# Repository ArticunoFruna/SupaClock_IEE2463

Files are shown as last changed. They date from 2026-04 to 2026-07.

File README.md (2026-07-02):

# SupaClock — Contexto y Guía del Proyecto

SupaClock es un sistema de salud inteligente usable (*wearable*) de pulsera desarrollado como parte del curso IEE2463. Su propósito es capturar biometría crítica en tiempo real, procesarla tanto en el dispositivo mediante técnicas de Inteligencia Artificial en el borde (TinyML), enviarla vía Bluetooth Low Energy (BLE) a una aplicación móvil de compañía y respaldarla de forma segura en la nube.

Este documento consolida el contexto general, características, funcionamiento de los sensores, arquitectura técnica y la organización del código según las tareas de desarrollo del proyecto.

---

## 1. Características Principales

*   **Procesamiento Concurrente y Multitarea:** Implementado bajo **ESP-IDF** (entorno oficial de Espressif) corriendo sobre **FreeRTOS** en un microcontrolador **Seeed Studio XIAO ESP32-S3** (y soportando el módulo **ESP32-C3 SuperMini** para captura de datos). Esto permite dividir el firmware en tareas con prioridades asignadas (adquisición de alta prioridad, procesamiento de actividad, interfaz gráfica e hilos de comunicación BLE).
*   **TinyML (Human Activity Recognition - HAR) en el Borde:** Inferencia en tiempo real de actividades físicas (Reposo, Caminar, Correr) ejecutada directamente en el reloj con un modelo de red neuronal convolucional 1D (CNN 1D) optimizado e integrado en C puro (`har_cnn1d`), operando con un muestreo del acelerómetro a 50 Hz.
*   **Interfaz Gráfica Integrada:** Pantalla LCD a color manejada mediante la librería gráfica **LVGL v8.4**, con refresco optimizado utilizando el bus SPI y **DMA (Direct Memory Access)** para liberar ciclos de procesamiento de la CPU.
*   **Aplicación Móvil Multiplataforma (Flutter & Dart):** 
    *   **Vista de Usuario:** Tablero interactivo con métricas en tiempo real, historial médico local e inicio de mediciones puntuales (*spot-checks*).
    *   **Procesamiento de Señales Local:** Incorpora el algoritmo **Pan-Tompkins** directamente en Dart para la detección de picos QRS y análisis de variabilidad del ritmo cardíaco (HRV) a partir de lecturas de ECG sin necesidad de servidores.
    *   **Modo Clínico:** Umbrales biométricos personalizables con lógica de estabilidad temporal para evitar falsas alarmas que disparan notificaciones locales y registros en la base de datos.
    *   **Modo Desarrollador Oculto:** Desbloqueado presionando 7 veces la versión en la pantalla de Configuración, otorgando acceso a flujos crudos de señales (ECG/IMU), grabación local a CSV e interfaz de comandos directos.
*   **Almacenamiento Local-First y Nube Serverless:** Almacenamiento local mediante Hive y sincronización asíncrona hacia Google Firebase (**Firestore** para métricas y **Storage** para las grabaciones CSV de electrocardiogramas completos), minimizando costes de infraestructura al no depender de Cloud Functions.

---

## 2. Sensores y Método de Funcionamiento

El dispositivo integra múltiples sensores biométricos conectados al bus físico común del microcontrolador.

### Resumen de Sensores
1.  **BMI160 (IMU - Unidad de Medición Inercial):** Acelerómetro y giroscopio conectados a través del bus **I2C**. Captura movimientos a 50 Hz para el algoritmo del podómetro (conteo de pasos) y para alimentar el modelo HAR en el borde.
2.  **AD8232 (ECG - Electrocardiograma):** Sensor analógico de pulso cardíaco de un solo canal. Se lee mediante el **ADC** interno del ESP32 a una frecuencia de muestreo de 500 Hz. Permite la visualización de la onda del electrocardiograma y el cálculo de intervalos RR.
3.  **MAX30102 (Pulsioxímetro):** Sensor óptico de ritmo cardíaco y saturación de oxígeno en sangre (SpO₂). Se comunica por **I2C**.
4.  **MAX30205 (Termómetro Clínico):** Sensor de temperatura de alta precisión diseñado para monitorización corporal humana. Se comunica por **I2C**.
5.  **MAX17048 (Fuel Gauge - Medidor de Batería):** Monitorea el voltaje y estado de carga de la batería Li-Po a través del bus **I2C**.

### Interfaz Física y buses de Comunicación
*   **Bus I2C (Compartido):** Los sensores BMI160, MAX30102, MAX30205 y MAX17048 comparten las líneas SDA y SCL del microcontrolador. Cada uno se identifica por su dirección de hardware hexadecimal única. Para evitar conflictos entre tareas concurrentes que acceden a este bus, el firmware emplea **Mutexes** de exclusión mutua de FreeRTOS.
*   **Bus SPI (Dedicado):** La pantalla LCD **ST7789** utiliza el bus SPI a alta velocidad con DMA para transferir buffers completos de píxeles generados en memoria RAM por LVGL.

### Protocolo de Comunicación BLE
El reloj actúa como servidor GATT y expone cuatro características principales bajo el protocolo biométrico de SupaClock:

| Característica UUID | Dirección | Descripción / Estructura del Dato |
| :--- | :--- | :--- |
| **`0xFF01`** | Notificación | **Flujo IMU Crudo:** Envío continuo a 50 Hz de paquetes de 12 bytes (`int16 ax, ay, az, gx, gy, gz`). |
| **`0xFF02`** | Notificación | **Métricas Agregadas (TLV):** Paquetes estructurados que contienen un encabezado y registros *Type-Length-Value* de variables (Ritmo cardíaco, SpO₂, Temperatura, Pasos, Batería, Estado HAR). |
| **`0xFF03`** | Notificación | **Flujo ECG Crudo:** Envío a 500 Hz de paquetes de 20 bytes que empaquetan 10 muestras consecutivas de ECG (`int16`). |
| **`0xFF04`** | Escritura | **Consola de Comandos:** Envío de órdenes al reloj (`0x00` detiene ECG, `0x01` inicia ECG, `0x02` activa depuración HAR, `0x03` detiene depuración). |

El formato **TLV (Type-Length-Value)** de la característica `0xFF02` estructura la información de la siguiente manera:
*   **Cabecera:** `Timestamp (u32)` + `Modo Energía (u8)` + `Longitud Datos (u8)`.
*   **Tipos de Registro (Types):**
    *   `0x01`: Frecuencia Cardíaca (BPM y calidad de señal).
    *   `0x02`: Saturación de Oxígeno (SpO₂ y calidad de señal).
    *   `0x03`: Temperatura Corporal.
    *   `0x04`: Estado de la Batería.
    *   `0x05`: Conteo de Pasos.
    *   `0x08`: Estado de Actividad HAR Consolidado.

---

## 3. Estructura de Directorios y Tareas de Desarrollo

El código fuente del proyecto se encuentra estructurado en carpetas dedicadas según el área de ingeniería y desarrollo:

```
SupaClock_IEE2463/
├── app/                  # Aplicación móvil en Flutter (Frontend y lógica del teléfono)
├── src/                  # Entrypoint del firmware y pruebas en ESP-IDF
├── lib/                  # Librerías internas y drivers de hardware para PlatformIO
├── hardware/             # Esquemáticos y PCB (diseño electrónico en Eagle/Kicad)
├── mechanical/           # Modelado en 3D del chasis y botón del reloj (OpenSCAD/STL)
├── tools/                # Scripts de Python para entrenamiento, simulaciones y debug
├── data_ml/              # Base de datos local de acelerometría para entrenamiento HAR
├── docs/                 # Hojas de datos (Datasheets), especificaciones y entregables
├── pc_simulator/         # Simulador de la interfaz gráfica en PC
└── scripts/              # Herramientas auxiliares y de generación de recursos gráficos
```

### 📂 Distribución de Tareas y Directorios de Trabajo

#### 1. Tareas de Firmware (C y C++ sobre ESP-IDF / FreeRTOS)
*   **Directorio principal de código:** [src/](file:///home/jay-c/Desktop/SupaClock_IEE2463/src) y [lib/](file:///home/jay-c/Desktop/SupaClock_IEE2463/lib)
*   **Configuración del entorno:** [platformio.ini](file:///home/jay-c/Desktop/SupaClock_IEE2463/platformio.ini) define los parámetros de compilación y dependencias.
*   **Controladores de sensores:** Ubicados en `lib/` bajo los nombres de cada driver:
    *   `bmi160_driver/` (Acelerómetro/Giroscopio)
    *   `max30102_driver/` (Pulsioximetría)
    *   `max30205_driver/` (Temperatura)
    *   `max17048_driver/` (Batería)
    *   `ad8232_driver/` & `ad8232_c3_driver/` (Electrocardiografía)
*   **Motor Gráfico (LVGL) y UI del Reloj:** Se trabaja en [lib/supaclock_ui/](file:///home/jay-c/Desktop/SupaClock_IEE2463/lib/supaclock_ui), [lib/ui_theme/](file:///home/jay-c/Desktop/SupaClock_IEE2463/lib/ui_theme) y [lib/ui_fonts/](file:///home/jay-c/Desktop/SupaClock_IEE2463/lib/ui_fonts).
*   **TinyML (CNN 1D) e Inferencia:** La lógica de red neuronal se encuentra en [lib/har_cnn1d/](file:///home/jay-c/Desktop/SupaClock_IEE2463/lib/har_cnn1d).
*   **Infraestructura BLE:** Las definiciones del protocolo e hilos de transmisión están en [lib/ble_telemetry/](file:///home/jay-c/Desktop/SupaClock_IEE2463/lib/ble_telemetry).
*   **Pruebas de Componentes:** Código para validar hardware de forma aislada en [src/tests/](file:///home/jay-c/Desktop/SupaClock_IEE2463/src/tests) (por ejemplo, tests de pantalla, BLE, sensores específicos o algoritmos particulares).

#### 2. Tareas de Desarrollo Móvil (Flutter & Dart)
*   **Directorio de trabajo:** [app/](file:///home/jay-c/Desktop/SupaClock_IEE2463/app)
*   **Interfaz de Usuario:** Vistas e interfaces en [app/lib/screens/](file:///home/jay-c/Desktop/SupaClock_IEE2463/app/lib/screens) (dashboard, settings, spot-check, dev-mode).
*   **Persistencia Local y Backend (Firebase):** Configuración de bases de datos y sincronización en [app/lib/services/](file:///home/jay-c/Desktop/SupaClock_IEE2463/app/lib/services) (`firestore_service.dart`, `storage_service.dart`, `local_store.dart` usando Hive).
*   **Procesamiento de Señal (ECG) y BLE:** Algoritmo Pan-Tompkins en `app/lib/services/pan_tompkins.dart` y parseo de tramas de telemetría en `app/lib/services/ble_service.dart`.
*   **Modelos de Datos:** Declarados en [app/lib/models/](file:///home/jay-c/Desktop/SupaClock_IEE2463/app/lib/models) para asegurar concordancia con Firebase.

#### 3. Tareas de Machine Learning y Análisis Científico (Python)
*   **Entrenamiento y Reentrenamiento HAR:** Los scripts para construir el modelo de actividad física se encuentran en [tools/train_har_cnn.py](file:///home/jay-c/Desktop/SupaClock_IEE2463/tools/train_har_cnn.py) y [tools/train_har_cnn_c3.py](file:///home/jay-c/Desktop/SupaClock_IEE2463/tools/train_har_cnn_c3.py).
*   **Recopilación de Datasets:** El historial de datasets recopilados clasificados para entrenar el clasificador se trabaja en [data_ml/](file:///home/jay-c/Desktop/SupaClock_IEE2463/data_ml) (ej. resting, walking, running, stairs).
*   **Reproducción y Debug del Modelo (Replay):** Script [tools/har_replay.py](file:///home/jay-c/Desktop/SupaClock_IEE2463/tools/har_replay.py) corre el modelo `.tflite` sobre logs de acelerometría y simula los filtros de suavizado.
*   **Calibración y Simulación de Umbrales:** `tools/calibrate_steps.py` (conteo de pasos) y `tools/debug_pt.py` (simulador Pan-Tompkins).
*   **Monitoreo del Hardware:** [tools/supaclock_monitor.py](file:///home/jay-c/Desktop/SupaClock_IEE2463/tools/supaclock_monitor.py) es una aplicación de escritorio para graficar ondas IMU/ECG y enviar comandos por puerto serie/BLE.

#### 4. Tareas de Diseño de Hardware (Electrónica / PCB)
*   **Directorio de trabajo:** [hardware/](file:///home/jay-c/Desktop/SupaClock_IEE2463/hardware)
*   Contiene los esquemáticos y placas (`.sch` y `.brd`) para el circuito portador del reloj, el módulo ECG AD8232 y el módulo medidor de batería, además de scripts de soporte de conexión como `build_v4_schematics.py` o `dump_nets.py`.

#### 5. Tareas de Diseño Mecánico (Carcasa y Botones)
*   **Directorio de trabajo:** [mechanical/](file:///home/jay-c/Desktop/SupaClock_IEE2463/mechanical)
*   Lugar donde se diseñan las cubiertas (superior, inferior y botones) en OpenSCAD (`.scad`) y se exportan a STL para manufactura mediante impresión 3D (`mechanical/stl/`, `mechanical/stl_v3/`).

#### 6. Tareas de Documentación del Proyecto
*   **Directorio de trabajo:** [docs/](file:///home/jay-c/Desktop/SupaClock_IEE2463/docs)
*   Incluye los manuales de arquitectura y conceptos (`docs/arquitectura_conceptos.md`), guías para nuevos desarrolladores (`docs/guia_introductoria.md`), protocolos de comunicación (`docs/ble_har_protocol.md`), resúmenes de avances e informes para las evaluaciones académicas del curso (`docs/Entrega1` a `docs/Entrega4`).

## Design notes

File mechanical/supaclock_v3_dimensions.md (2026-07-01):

# SupaClock V3 — Hoja de cotas

Análoga a `supaclock_v2_dimensions.md`. Cambios clave vs V2:

- Altura total reducida de **25 mm → 17 mm** (XIAO SMD soldado directo, sin pin sockets).
- Bottom case **al ras** (sin pocket de pila). Standoffs reducidos a la mitad (1 mm vs 2 mm).
- Pila Sony WF-1000XM5 case (prismática ~30 × 20 × 5 mm) **colgada del techo** con cinta 3M VHB doble faz (0.5 mm) sobre la zona del display.
- Top case con sistema **plug-and-play** para faceplate intercambiable (snap-fit ó magnetic).
- Botones laterales V2 (stem horizontal) **inalterados**: switch nuevo 3×7×3.5 mm side-press pegado plano sobre la PCB con super-glue gel, plunger apuntando a +X, cables soldados a pads SMD originales.
- Heat-set inserts M3 para tornillería desmontable (igual que V2: Ø4.2 × 5 mm).

Todas las medidas en milímetros.

---

## 1. Sistema de coordenadas

Idéntico a V2:

```
            Z (vertical, hacia arriba)
            |
            |
            +------ X (largo, eje izq-der del reloj puesto)
           /
          /
         Y (corto, eje proximal-distal en la muñeca)

Origen: esquina INFERIOR-IZQUIERDA-FRENTE del envelope exterior
```

- **Bottom case**: Z = 0 a Z = 3 (cara Z=0 toca la piel)
- **Seam (unión)**: plano horizontal en Z = 3
- **Top case**: Z = 3 a Z = 17 (en frame top-case-local: Z = 0 a 14)
- **Faceplate** (cosmético, intercambiable): Z = 17 a Z = 19 (sumando 2 mm de techo decorativo)

Conversión PCB-local ↔ case-local:
```
X_case = X_pcb + pcb_off_x = X_pcb + 6.5
Y_case = Y_pcb + pcb_off_y = Y_pcb + 6.0
```

---

## 2. Envelope exterior

| Parámetro | Valor | Notas |
|---|---|---|
| Ancho (X) | 98.0 mm | base. Top está INSET por `taper` |
| Largo (Y) | 79.0 mm | base. Top está INSET por `taper` |
| **Alto (Z) core** | **17.0 mm** | core sin faceplate (vs V2 25.0) |
| Alto con faceplate snap | 19.0 mm | +2 mm de skin decorativo |
| Alto con faceplate magnetic | 19.0 mm | idem |
| r_vert | 12.0 mm | radio de las 4 esquinas verticales |
| r_chamfer | 1.5 mm | chamfer en Z=0 y Z=15.5 |
| taper | 2.0 mm | reducción lineal radio entre Z=0 y Z=15.5 |

---

## 3. Bottom case — features (al ras)

| Feature | Posición (X, Y) | Z | Dimensiones | Notas |
|---|---|---|---|---|
| Piso | toda la base | 0 — 2 | 2 mm grosor | esquinas redondeadas |
| Cavidad | toda | 2 — 3 | abierta arriba | offset 2 mm desde envelope |
| Standoff MH1 | (10.0, 69.5) | 2 — 3 | Ø7 OD, Ø3.2 ID | **1 mm** (mitad de V2) |
| Standoff MH2 | (88.0, 69.5) | 2 — 3 | Ø7 OD, Ø3.2 ID | idem |
| Standoff MH3 | (10.0, 9.5) | 2 — 3 | Ø7 OD, Ø3.2 ID | idem |
| Standoff MH4 | (88.0, 9.5) | 2 — 3 | Ø7 OD, Ø3.2 ID | idem |
| Cutout MAX30102 | centro (52.0, 39.195) | 0 — 2 | **17 × 22 mm (X×Y)** | sensor PPG, rotado 90° vs V2 (lado largo en Y) para calzar orientación real del sensor en PCB v3 |
| Cutout MAX30205 | centro (51.5, 23.0) | 0 — 2 | 14 × 10 mm | sensor temp |
| Electrode RA | centro (18.5, 37.5) | 0 — 2 | Ø6 mm | M3 a piel |
| Electrode LA | centro (72.0, 38.0) | 0 — 2 | Ø6 mm | M3 a piel |
| Electrode RL | centro (50.0, 10.0) | 0 — 2 | Ø6 mm | M3 a piel |

**Sin pocket de pila** → cara contra la piel completamente plana.

---

## 4. Top case core — features

Frame local: Z=0 = seam, Z=14 = cara exterior del techo (cubierta por el faceplate).

| Feature | Posición (X, Y) | Z (local top) | Dimensiones | Notas |
|---|---|---|---|---|
| Cavidad | toda | 0 — 12 | abierta abajo | techo a Z=12, interior alcanza 12 |
| Techo | toda | 12 — 14 | 2 mm grosor | con ventana display |
| Pilar P1-P4 (4) | (10/88, 9.5/69.5) | 0 — 12 | Ø7 OD, Ø4.2 ID × 5 mm | heat insert M3 (insert depth 5) |
| **Ventana display** | centro (50.78, 44.5) | 10 — 14 | **28 × 34 mm** | atraviesa techo + faceplate alineado |
| Botón SW1 | (96, 21.375, btn_z=3.5) | 3.5 ± 2.1 | Ø4.2 mm | atraviesa pared +X, eje X (V2 idéntico) |
| Botón SW2 | (96, 33.875, btn_z=3.5) | 3.5 ± 2.1 | Ø4.2 mm | idem (V2 idéntico) |
| **USB-C** | (96, 54, usb_z=3.6) | 3.6 ± 3.5 | 13 × 7 mm rect | pared +X. **z_above_pcb reducido a 2** vs V2 (14) por XIAO SMD soldado |
| **Jack 3.5 ECG** | (0, 24.586, jack_z=6.1) | 6.1 ± 3.25 | Ø6.5 thread pasante + Ø12 rebaje (prof 1 mm en la pared) | pared **-X**. Mismo `jack_y_pcb` que V2; `z_above_pcb` bajado de 12.6 → 4.5. Rebaje **NO atraviesa** la pared (deja 1 mm interior con solo el thread). Conecta a J13 PCB v3 vía cables manuales |
| **Marca VHB pila** | centro (50.78, 44.5) | 12 (cara interior techo) | 30 × 20 mm rectángulo | indentación 0.3 mm de profundidad para guiar la cinta VHB |

> **Tabs L para la pila — DESHABILITADOS en V3.1.** La zona donde irían los tabs (X=35–67, Y=34–55) coincide con la huella del display + adapter PCB y puede colisionar. Hasta confirmar medidas reales del PCB+adapter, sólo dejamos la marca VHB. El código `battery_tab()` y `battery_tabs_all()` se preserva en el SCAD comentado para reactivar cuando se confirme el clearance.

### 4.1 Retention faceplate — V3.3 diagonal limpia

**Esquema diagonal SW-NE**: solo 2 imanes redondos en la diagonal SW-NE. Las otras 2 esquinas (SE-NW) **quedan limpias, sin agujeros**. Sin pines guía.

#### Modo MAGNETIC

| Parámetro | Valor |
|---|---|
| Imanes | **2 pares de N42 Ø7 × 1.5 mm** (4 total, diámetro = cabeza M4) |
| Posición imanes | esquinas **SW y NE** (diagonal), a 6 mm del borde |
| Hueco imán | Ø7.2 × 1.6 mm (holgura 0.2/0.1) |
| Otras 2 esquinas (SE, NW) | **sin features** (lisas) |
| Fuerza atracción por par | ~0.7 kg |
| Fuerza total ensamble | ~1.4 kg |
| Ciclos | infinitos |
| Alineación angular | los 2 imanes en diagonal restringen rotación; el ajuste perimetral del faceplate al borde del core complementa |
| Polaridad | N hacia arriba en core, S hacia abajo en face |
| Fijación imán | super-glue gel dentro del hueco |
| Tapa cosmética | 0.4 mm de PLA debajo del imán en core (techo 2 mm, hueco 1.6) |

#### Modo SNAP

| Parámetro | Valor PLA eSun PLA+ |
|---|---|
| Cantilevers | **4 idénticos** (faceplate macho, core hembra) |
| Cantilever largo × espesor | 5 × 1.4 mm |
| Hook engagement | 0.4 mm |
| Fillet base | 0.5 mm |
| Insertion / extraction | ~5 N / ~9 N |
| Ciclos | 30–40 |

---

## 5. Faceplate (skin intercambiable)

Pieza separada, snap o magnetic. Z=17 a Z=19.

| Feature | Posición | Dimensiones | Notas |
|---|---|---|---|
| Slab base | toda | 98 × 79 × 1.5 mm | sigue contorno del top exterior (radio 10 mm = r_vert − taper) |
| Ventana display | centro (50.78, 44.5) | 28 × 34 mm (alineada con techo core) | atraviesa todo el faceplate |
| Bezel display | anillo alrededor de la ventana | 32 × 38 mm exterior, 28 × 34 interior | recess 0.3 mm para "vidrio" cosmético |
| Marcas horarias / decoración | según `style` | grabadas 0.4 mm de profundidad | mode-dependiente |
| Retention macho (snap) | 4 cantilevers internos | 5 mm largo × 1.4 mm espesor | cuando `retention=snap` |
| Cavidades imanes (magnetic) | 4 huecos esquinas | Ø5.2 × 2.1 mm | cuando `retention=magnetic` |
| Pin guía | 2 cilindros Ø2 mm | sale de la cara inferior 3 mm | siempre presente |

### 5.1 Variantes de estilo

- **`style="minimal"`**: PLA Black, sin decoración, sólo bezel display.
- **`style="classic"`**: bezel display + 12 marcas horarias (Ø1 mm cada una) a 16 mm del centro, grabadas 0.4 mm. Color sugerido: PLA Silver/Grey.
- **`style="sport"`**: bezel display + numerales 5/15/25/35/45/55 en relieve negativo a 18 mm del centro. Color sugerido: PLA Orange.

---

## 6. Pila colgada del techo

Pila Sony WF-1000XM5 case (~30 × 20 × 5 mm, LiPo prismática) **con conector JST PH 2.0 mm** previamente soldado.

| Item | Valor |
|---|---|
| Posición de la pila (cara interior techo) | centrada en (50.78, 44.5) en case-local |
| Footprint | 30 × 20 mm |
| Altura pila | 5 mm |
| Adhesivo | cinta 3M VHB 5952 (0.5 mm espesor) doble faz |
| Marca en el techo | indentación rectangular 0.3 mm de profundidad para guiar el VHB |
| Salida cable JST | lado **-X** de la pila → recorrido ~25 mm hasta MAX17048 en (~17, 50) PCB-local |
| Gap pila ↔ display | ~1.5 mm (pila a Z=7..12, display a Z=1.6..5.6 en top-local) |

**Importante**: NO pegar con cyanoacrylate sobre la pila (riesgo térmico). VHB de doble faz es la opción correcta para baterías LiPo.

---

## 7. Stack vertical detallado

```
Z = 17.0  ── cara exterior FACEPLATE ──
Z = 15.0     base FACEPLATE (1.5 mm slab + 0.5 retention)
Z = 15.0  ── cara exterior TECHO core ──
Z = 13.0     espesor techo
Z = 13.0  ── cara interior techo ──
Z = 12.5     VHB 3M (0.5 mm)
Z = 12.5  ── cara superior pila ──
Z = 7.5      pila (5 mm)
Z = 7.5   ── cara inferior pila ──
Z = 6.0      gap pila ↔ display (1.5 mm)
Z = 6.0   ── cara superior display ──
Z = 4.6      display + adapter (1.6 + 2.4)
Z = 4.6   ── cara superior PCB ──
Z = 3.0      PCB FR-4 (1.6 mm)
Z = 3.0   ── cara inferior PCB / seam ──
Z = 2.0      standoff (1 mm, mitad de V2)
Z = 2.0   ── cara interior bottom ──
Z = 0.0      piso bottom (2 mm)
Z = 0.0   ── cara contra PIEL ──
```

(Heights en frame **abs**, no top-local).

---

## 8. Standard parts (compra fuera)

| Parte | Especificación | Cant | Notas |
|---|---|---|---|
| Perno M3 | M3 × 6 mm cabeza redondeada | 4 | bottom → top via heat insert |
| Heat insert M3 | M3 × 5 mm OD Ø4.0–4.2 | 4 | embebidos en pilares top |
| Spring bar | Ø1.5 × largo 22 mm | 4 | tienda relojes |
| Correa | 20 mm cualquier estilo | 1 | tienda relojes |
| Perno M3 (electrodo) | M3 × 8 mm acero inox cabeza redonda | 3 | electrodos ECG |
| Tuerca M3 (electrodo) | M3 estándar | 3 | electrodos ECG |
| Imán neodimio N42 | Ø5 × 2 mm | 4 | sólo si `retention=magnetic` |
| Cinta VHB 3M 5952 | 0.5 mm doble faz | 30 × 20 mm | pila colgada |
| Switch tactile | 3 × 7 × 3.5 mm side-press SMD | 2 | el que ya tenés |
| Cable 30 AWG | flexible silicone | 4× 30 mm | soldar switch nuevo a pads SMD |
| Super-glue gel | cyanoacrylate gel | 1 frasco | pegar switches PLANOS sobre PCB |

---

## 9. Validación rápida

| Verificación | Valor esperado |
|---|---|
| Ancho exterior máximo (Z=0) | 98.0 |
| Ancho exterior máximo (Z=15) | 94.4 (= 98 − 2 × taper × 15/17) |
| H_total core | 17.0 |
| H_total con faceplate | 19.0 |
| Distancia entre lugs (inner mismo lado) | 20.0 |
| Distancia entre standoffs MH1-MH2 | 78.0 |
| Altura interior arriba del PCB | 10.4 |
| Distancia desde piel (Z=0) al centro del display | 6.5 |
| Distancia desde piel al centro USB-C | 4.6 (= 3 + 1.6) |
| Volumen aproximado del case completo | ~75 cm³ |

---

*Archivos relacionados:*
- `supaclock_v3_bottom_case.scad`
- `supaclock_v3_top_case.scad`
- `supaclock_v3_faceplate.scad`
- `supaclock_v3_button_caps.scad` (reuse del v2)
- `supaclock_v3_assembly.scad`

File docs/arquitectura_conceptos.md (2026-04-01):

# Guía Completa: Arquitectura y Conceptos del Proyecto SupaClock

Esta guía está diseñada para llevar a un programador con conocimientos básicos (por ejemplo, alguien que ha utilizado la plataforma Arduino y la función `loop()`) hacia el entendimiento de una arquitectura profesional utilizando un Sistema Operativo en Tiempo Real (RTOS), desarrollo móvil moderno y bases de datos en la nube.

---

## 1. De Arduino a ESP-IDF (FreeRTOS)

En un programa clásico de Arduino, el código funciona de manera **secuencial**: hay un `setup()` que inicializa los pines y un `loop()` infinito que se repite una y otra vez. El problema de esta estrategia (llamada "Super-Loop") es que si utilizas un `delay()` o si la lectura de un sensor tarda mucho, **todo el sistema se congela**. No puedes actualizar la pantalla y medir la frecuencia cardíaca al mismo tiempo.

Para solucionar esto, SupaClock no usa el entorno básico de Arduino, sino que usa **ESP-IDF** (el entorno oficial de Espressif en lenguaje C puro) operando sobre **FreeRTOS** (Free Real-Time Operating System).

### ¿Qué es FreeRTOS y sus Tareas?
FreeRTOS es un mini-sistema operativo para microcontroladores. Nos permite dividir nuestro código en **Tareas (Tasks)**, como si tuviéramos múltiples `loop()` ejecutándose al mismo tiempo (Multitasking o Concurrencia). 
El ESP32-C3 solo tiene un "procesador" (un solo núcleo), pero FreeRTOS cambia tan rápido de una tarea a otra (en milisegundos) que parece que todo ocurre a la vez.

En SupaClock se definen tareas con **prioridades**:
1. **Tarea de Adquisición (Prioridad Alta):** Constantemente lee los sensores. Como medir el pulso o la temperatura es crítico, si esta tarea necesita funcionar, FreeRTOS pausa a las demás de inmediato y le presta el procesador.
2. **Procesamiento Edge (Prioridad Media):** Aplica matemáticas a lo que leyó la tarea anterior (ej. contar pasos, deducir la postura con *TinyML*).
3. **Interfaz Gráfica (Prioridad Media-Baja):** Dibuja los números en la pantalla LCD (LVGL) y lee cuando oprimes un botón.
4. **Comunicaciones BLE (Prioridad Baja):** Se encarga de empaquetar y enviar inalámbricamente los resultados por Bluetooth.

### Protegiendo la Memoria: Queues y Mutexes
Al tener cosas pasando "al mismo tiempo", hay riesgos:
* **El problema:** ¿Qué pasa si la Tarea 1 intenta guardar datos en una variable, y justo en ese milisegundo la Tarea 2 intenta leer esa misma variable? Podría leer basura.
* **Solución 1 (Queues o Colas):** Son buzones de mensajes de FreeRTOS. La Tarea de Adquisición lee 50 valores del acelerómetro y los mete en un buzón de forma segura. La Tarea de Procesamiento los saca del buzón uno a uno para analizarlos.
* **Solución 2 (Mutex):** "Mutex" significa Exclusión Mutua. Funciona como la **llave del baño**. Si tenemos tres sensores conectados al mismo cable físico (I2C) y la Tarea 1 quiere leer un sensor, toma la llave (Mutex). Si durante ese instante la Tarea 3 quiere leer otro sensor del mismo cable, debe cruzar los brazos y esperar a que la Tarea 1 suelte la llave. Así evitamos colisiones catastróficas.

---

## 2. Conceptos de Hardware y Protocolos (Explicado desde cero)

Tu microcontrolador ESP32-C3 tiene un número muy limitado de pines físicos. Si intentas conectar 4 sensores avanzados asignando cables y pines separados para cada dato, te quedarías sin pines casi de inmediato. Por ello, se utilizan "Protocolos de Bus", que permiten compartir cables entre muchos chips.

### Bus I2C (Inter-Integrated Circuit)
Se podría traducir como el "Bus de 2 cables". Es un protocolo donde todos los sensores biométricos de SupaClock comparten **solo 2 cables**:
1. **SCL (Reloj):** El cable donde el ESP32 marca el ritmo o velocidad de la conversación.
2. **SDA (Datos):** El cable por donde viajan los "1s y 0s" (los mensajes).

**¿Cómo funciona si todos comparten el mismo cable?**
Funciona como si el ESP32 fuera el profesor de una sala de clases, y cada sensor es un alumno con un "nombre" numérico único (Llamado **Dirección Hexadecimal**). 
Si el ESP32 grita por el cable SDA: *"¡Alumno 0x57, entrégame tu tarea!"*, solo el Oxímetro (MAX30102) le responde, mientras el Termómetro (MAX30205, dirección `0x48`) ignora el mensaje. 
Esto permite conectar el Oxímetro, el Termómetro, el Giroscopio y el Medidor de Batería, usando solamente 2 pines del ESP32.

### Bus SPI (Serial Peripheral Interface)
I2C es genial para sensores, pero es muy lento para mover gráficos hacia una pantalla a color. Para la pantalla LCD ST7789, usamos SPI.
SPI usa más cables que I2C, pero es una vía rápida dedicada que opera como una autopista de varias pistas:
* **SCK:** El ritmo de reloj (mucho más rápido que I2C).
* **MOSI:** El canal de ida (Master Out, Slave In). El ESP32 le escupe píxeles de colores a la pantalla por aquí.
* **CS (Chip Select):** Un cable extra que actúa como un "switch". Cuando el ESP32 lo pone en LOW, le dice a la pantalla *"Hey, pon atención que lo que va a pasar por el cable MOSI es una foto para ti"*. 

### El DMA (Direct Memory Access)
Imagina que eres un arquitecto construyendo un muro muy largo. Podrías tomar ladrillo por ladrillo y llevarlo caminando (es decir, el procesador del ESP32 lee un píxel de su memoria y lo manda a la pantalla, uno a uno). Si lo haces así, tú (la CPU del ESP32) no puedes hacer nada más; estás esclavizado llevando píxeles.

El **DMA** es como contratar a un ayudante por hardware físico. El código del ESP32 (usando una librería gráfica llamada LVGL) "dibuja" en su memoria interna una imagen completa de la pantalla. Luego, el ESP32 le dice al DMA: *"Hey DMA, toma todos estos 10.000 píxeles y bombéalos hacia la pantalla por la vía SPI lo más rápido que puedas. Yo me voy a seguir midiendo la actividad cardíaca."*
El resultado: la pantalla se refresca de la nada, fluidamente, sin costarle recursos valiosos de cálculo matemático a la CPU.

### ADC (Conversor Análogo a Digital)
El mundo real no son `1` ni `0`; la corriente eléctrica de tu corazón es analógica (como una ola infinita y suave). El chip encargado del ECG (AD8232) extrae tus latidos tocando los tornillos metálicos, y saca un pequeñito voltaje que sube y baja.
El **ADC** del ESP32 es la compuerta que lee esa olita de voltaje y, miles de veces por segundo, la convierte a números enteros (ej. de 0 a 4095) para que el código en C la pueda entender y matemáticas.

---

## 3. El Mundo Móvil: App y Flutter (Explicado desde cero)

### ¿Qué es Flutter y por qué se usa?
Tradicionalmente, si querías crear una App para que se conecte a un de hardware, necesitas saber programar en **Kotlin o Java** (para teléfonos Android) y otro código completamente distinto en **Swift** (para iPhones). Esto dobla el trabajo.
**Flutter** es una herramienta moderna creada por Google utilizando el lenguaje de programación **Dart**. Nos permite diseñar una aplicación escribiendo el código de las pantallas **una sola vez**, y Google se encarga de compilar ese código para que funcione de forma idéntica en Android e iOS.
En Flutter todo es un "Widget". Un botón es un widget que va dentro de una Lista, que es un widget, que va dentro de una Ventana (widget). Modificar pantallas móviles consiste en agrupar visualmente estas cajas de construcción abstractas.

### ¿Cómo se comunican el Reloj y el Celular? (Bluetooth BLE)
Se utiliza un protocolo llamado **Bluetooth Low Energy (BLE)**, el cual es muy diferente al Bluetooth clásico de los audífonos (que chupan muchísima batería al estar siempre activos transmitiendo audio).

El BLE opera mediante la lectura de "pizarras":
* **El Servidor (SupaClock):** El ESP32 funciona como una pizarra dividida en secciones lógicas (llamadas **Servicios**). En la sección 'Batería' escribe un '80%'. En la sección 'Frecuencia Cardíaca' escribe '90 ppm'. Estas cajitas pequeñas donde escribe los números exactos se llaman **Características GATT**.
* **El Cliente (La App del Celular):** El teléfono encuentra el reloj, se conecta, y no pide la información cada 5 minutos, sino que **se subscribe** a la característica de 'Frecuencia Cardíaca'.
* **Notificaciones:** El reloj actualiza el texto en su "pizarra" solo 1 vez por segundo (1 Hz). Cuando el número cambia a '91 ppm', pasivamente la antena le "notifica" (Notify) a la App del celular para que mueva sus gráficos. Es un diseño altamente ahorrativo en batería.

---

## 4. El Backend y la Nube: Firebase (Explicado desde cero)

### ¿Qué es el "Backend" y qué es "Serverless"?
Al construir una app completa, necesitas un puente permanente que guarde en la nube los registros del reloj para que no se pierdan cuando el celular se apague. Históricamente tendrías que arrendar una torre de computadora real en Amazon (un "Servidor"), instalar Linux, configurar una base de datos MySQL, gestionar la seguridad, y rezar para que si se corta su luz, puedas reiniciarlo.

**Firebase** es un ecosistema de Google enfocado en la arquitectura "Serverless" (Sin Servidor propio). En este formato, tú no configuras una computadora virtual, ni sabes en qué parte física del mundo corre tu código, sino que Google te da las herramientas mágicas listas para usar: "Aquí tienes un inicio de sesión que no se cae nunca, aquí almacenas datos como un diccionario gigante, y me pagas solo por los datos consumidos, olvídate del mantenimiento". 

### A. Cloud Firestore (Base de Datos NoSQL)
Existen bases de datos tipo SQL (relacionales), parecidas a una planilla de Excel inmensa donde todo debe encajar en columnas rígidas ('ID', 'Nombre', 'Hobby').
**Firestore** rompe esto siendo **NoSQL**; organiza los datos mediante "Documentos".
Imagina organizar tu escritorio:
* Abres una carpeta que dice **`Usuarios`**. (Esto Firebase le llama una "Colección").
* En la carpeta encuentras miles de hojas de papel con un nombre, como **`tomas_avendaño_123`**. (Esto se llama un "Documento").
* En el documento de Tomás, hay puro texto formateado estilo diccionario (JSON): "Edad: 24, Pasos de Hoy: 4000".
Su utilidad radica en la flexibilidad inmensa, pudiendo organizar datos biológicos por meses y años de una manera casi idéntica a carpetas y archivos locales, sin obligar al programa a ser tan rígido.

### B. Firebase Authentication
¿Cómo garantizamos la seguridad de que el usuario Pedro no vea el registro de ritmo cardíaco del usuario Juan en la nube? 
Firebase Authentication otorga de caja un login automatizado. La app de Flutter le tira a la cajita mágica de Google un correo y una contraseña; Google verifica y se encarga de todo lo difícil, y si la contraseña es correcta, devuelve un "Ticket Secreto (Token)". La App muestra este Token cada vez que le pide un dato a la base de Datos Firestore. Así blindamos toda la información biomédica sin codificar sistemas robustos de criptografía por nosotros mismos.

### C. Cloud Functions (Y el Algoritmo del ECG)
Un ESP32 (el cerebro del reloj) mide unos 2 centímetros; es lo bastante poderoso para dibujar tu pantalla y medir si el acelerómetro saltó, peeeeeero... 
Si quisiéramos analizar matemáticamente durante largo rato la derivativa médica de tu Electrocardiograma (usando el complejo algoritmo de Pan-Tompkins para atenuar tu respiración y hallar la variabilidad de los latidos pura), el microcontrolador llegaría al tope, se congelaría por el esfuerzo matemático flotante o, derechamente, agotaría su micropila de batería muy velozmente.

**La solución es la Nube:**
El reloj captura el Vector del ECG puro en datos brutos (RAW), los envía por la baja energía del Bluetooth a la App de Flutter, y la App los despacha masivamente hacia Google Firebase.
Apenas llegan a la nube de Firebase, ocurre la magia de las **Cloud Functions**: Estas son programas o "Scripts" en la nube (generalmente escritos con código **Python**) que Google dispara automáticamente como si fuera el percutor de una pistola. Una de estas funciones ocultas "despierta", recibe este gigantesco lote de datos cardíacos sucios, y ejecuta todo el filtro complejo usando la potencia infinita de los mega procesadores de Google Data Centers. Genera el resultado médico limpio, lo incrusta de vuelta en la base de datos Firestore de ese usuario, y se "apaga". Finalmente la App en tu celular escucha esto, y muestra tu Electrocardiograma perfecto sin que el reloj haya sufrido estrés alguno.

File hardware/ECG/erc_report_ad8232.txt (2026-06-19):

ERC report (2026-06-16T16:34:21, Encoding UTF8)
Report includes: Errors, Warnings

***** Sheet /
[wire_dangling]: Wires not connected to anything
    ; error
    @(63.50 mm, 147.32 mm): Horizontal Wire, length 10.16 mm
[wire_dangling]: Wires not connected to anything
    ; error
    @(71.12 mm, 147.32 mm): Horizontal Wire, length 2.54 mm
[wire_dangling]: Wires not connected to anything
    ; error
    @(101.60 mm, 58.42 mm): Vertical Wire, length 5.08 mm
    @(101.60 mm, 53.34 mm): Horizontal Wire, length 2.54 mm
[wire_dangling]: Wires not connected to anything
    ; error
    @(121.92 mm, 73.66 mm): Horizontal Wire, length 20.32 mm
[wire_dangling]: Wires not connected to anything
    ; error
    @(121.92 mm, 78.74 mm): Horizontal Wire, length 20.32 mm
[wire_dangling]: Wires not connected to anything
    ; error
    @(124.46 mm, 121.92 mm): Vertical Wire, length 17.78 mm
    @(124.46 mm, 104.14 mm): Horizontal Wire, length 2.54 mm
[wire_dangling]: Wires not connected to anything
    ; error
    @(129.54 mm, 53.34 mm): Vertical Wire, length 45.72 mm
    @(134.62 mm, 55.88 mm): Horizontal Wire, length 63.50 mm
[wire_dangling]: Wires not connected to anything
    ; error
    @(137.16 mm, 124.46 mm): Horizontal Wire, length 2.54 mm
    @(139.70 mm, 124.46 mm): Horizontal Wire, length 2.54 mm
[wire_dangling]: Wires not connected to anything
    ; error
    @(139.70 mm, 68.58 mm): Vertical Wire, length 7.62 mm
    @(139.70 mm, 60.96 mm): Horizontal Wire, length 17.78 mm
[wire_dangling]: Wires not connected to anything
    ; error
    @(139.70 mm, 83.82 mm): Horizontal Wire, length 2.54 mm
    @(139.70 mm, 86.36 mm): Vertical Wire, length 2.54 mm
[wire_dangling]: Wires not connected to anything
    ; error
    @(139.70 mm, 104.14 mm): Horizontal Wire, length 2.54 mm
    @(137.16 mm, 104.14 mm): Horizontal Wire, length 2.54 mm
[wire_dangling]: Wires not connected to anything
    ; error
    @(142.24 mm, 93.98 mm): Horizontal Wire, length 2.54 mm
    @(137.16 mm, 93.98 mm): Vertical Wire, length 2.54 mm
[power_pin_not_driven]: Input Power pin not driven by any Output Power pins
    ; error
    @(162.56 mm, 147.32 mm): Symbol #GND1 Pin 1 [GND, Power input, Line]
[wire_dangling]: Wires not connected to anything
    ; error
    @(182.88 mm, 78.74 mm): Horizontal Wire, length 15.24 mm
    @(124.46 mm, 93.98 mm): Vertical Wire, length 43.18 mm
[wire_dangling]: Wires not connected to anything
    ; error
    @(185.42 mm, 60.96 mm): Vertical Wire, length 7.62 mm
    @(165.10 mm, 60.96 mm): Horizontal Wire, length 20.32 mm
[wire_dangling]: Wires not connected to anything
    ; error
    @(187.96 mm, 86.36 mm): Horizontal Wire, length 5.08 mm
    @(203.20 mm, 86.36 mm): Vertical Wire, length 2.54 mm
[power_pin_not_driven]: Input Power pin not driven by any Output Power pins
    ; error
    @(194.31 mm, 93.98 mm): Symbol #SUPPLY1 Pin 1 [3.3V, Power input, Line]
[wire_dangling]: Wires not connected to anything
    ; error
    @(198.12 mm, 127.00 mm): Vertical Wire, length 2.54 mm
    @(182.88 mm, 114.30 mm): Horizontal Wire, length 10.16 mm
[footprint_link_issues]: The current configuration does not include the footprint library 'AD8232_Heart_Rate_Monitor'
    ; warning
    @(20.32 mm, 203.20 mm): Symbol FRAME1 [FRAME-LETTER]
[footprint_link_issues]: The current configuration does not include the footprint library 'AD8232_Heart_Rate_Monitor'
    ; warning
    @(45.72 mm, 55.88 mm): Symbol JP1 [M03PTH]
[footprint_link_issues]: The current configuration does not include the footprint library 'AD8232_Heart_Rate_Monitor'
    ; warning
    @(48.26 mm, 147.32 mm): Symbol SJ4 [SOLDERJUMPERTRACE]
[footprint_link_issues]: The current configuration does not include the footprint library 'AD8232_Heart_Rate_Monitor'
    ; warning
    @(50.80 mm, 116.84 mm): Symbol JP3 [M06SIP]
[footprint_link_issues]: The current configuration does not include the footprint library 'AD8232_Heart_Rate_Monitor'
    ; warning
    @(63.50 mm, 58.42 mm): Symbol JP2 [AUDIO-JACKSMD2]
[footprint_link_issues]: The current configuration does not include the footprint library 'AD8232_Heart_Rate_Monitor'
    ; warning
    @(63.50 mm, 101.60 mm): Symbol R15 [10KOHM1/10W1%(0603)0603]
[footprint_link_issues]: The current configuration does not include the footprint library 'AD8232_Heart_Rate_Monitor'
    ; warning
    @(68.58 mm, 147.32 mm): Symbol D1 [LED-RED0603]
[footprint_link_issues]: The current configuration does not include the footprint library 'AD8232_Heart_Rate_Monitor'
    ; warning
    @(78.74 mm, 147.32 mm): Symbol R16 [1K-1%]
[footprint_link_issues]: The current configuration does not include the footprint library 'AD8232_Heart_Rate_Monitor'
    ; warning
    @(93.98 mm, 53.34 mm): Symbol R17 [0OHM1/10W5%(0603)]
[footprint_link_issues]: The current configuration does not include the footprint library 'AD8232_Heart_Rate_Monitor'
    ; warning
    @(101.60 mm, 66.04 mm): Symbol R1 [RESISTOR0603-RES]
[footprint_link_issues]: The current configuration does not include the footprint library 'AD8232_Heart_Rate_Monitor'
    ; warning
    @(109.22 mm, 53.34 mm): Symbol R18 [0OHM1/10W5%(0603)]
[footprint_link_issues]: The current configuration does not include the footprint library 'AD8232_Heart_Rate_Monitor'
    ; warning
    @(109.22 mm, 66.04 mm): Symbol R2 [RESISTOR0603-RES]
[footprint_link_issues]: The current configuration does not include the footprint library 'AD8232_Heart_Rate_Monitor'
    ; warning
    @(116.84 mm, 73.66 mm): Symbol R3 [RESISTOR0603-RES]
[footprint_link_issues]: The current configuration does not include the footprint library 'AD8232_Heart_Rate_Monitor'
    ; warning
    @(116.84 mm, 78.74 mm): Symbol R4 [RESISTOR0603-RES]
[footprint_link_issues]: The current configuration does not include the footprint library 'AD8232_Heart_Rate_Monitor'
    ; warning
    @(116.84 mm, 91.44 mm): Symbol R5 [RESISTOR0603-RES]
[footprint_link_issues]: The current configuration does not include the footprint library 'AD8232_Heart_Rate_Monitor'
    ; warning
    @(124.46 mm, 99.06 mm): Symbol R6 [RESISTOR0603-RES]
[footprint_link_issues]: The current configuration does not include the footprint library 'AD8232_Heart_Rate_Monitor'
    ; warning
    @(124.46 mm, 124.46 mm): Symbol C1 [CAP0603-CAP]
[footprint_link_issues]: The current configuration does not include the footprint library 'AD8232_Heart_Rate_Monitor'
    ; warning
    @(132.08 mm, 104.14 mm): Symbol R7 [RESISTOR0603-RES]
[footprint_link_issues]: The current configuration does not include the footprint library 'AD8232_Heart_Rate_Monitor'
    ; warning
    @(137.16 mm, 119.38 mm): Symbol R8 [RESISTOR0603-RES]
[footprint_link_issues]: The current configuration does not include the footprint library 'AD8232_Heart_Rate_Monitor'
    ; warning
    @(139.70 mm, 91.44 mm): Symbol C2 [CAP0603-CAP]
[footprint_link_issues]: The current configuration does not include the footprint library 'AD8232_Heart_Rate_Monitor'
    ; warning
    @(139.70 mm, 106.68 mm): Symbol C3 [CAP0603-CAP]
[footprint_link_issues]: The current configuration does not include the footprint library 'AD8232_Heart_Rate_Monitor'
    ; warning
    @(139.70 mm, 129.54 mm): Symbol R9 [RESISTOR0603-RES]
[footprint_link_issues]: The current configuration does not include the footprint library 'AD8232_Heart_Rate_Monitor'
    ; warning
    @(147.32 mm, 175.26 mm): Symbol LOGO1 [OSHW-LOGOS]
[footprint_link_issues]: The current configuration does not include the footprint library 'AD8232_Heart_Rate_Monitor'
    ; warning
    @(162.56 mm, 60.96 mm): Symbol C4 [CAP0805]
[footprint_link_issues]: The current configuration does not include the footprint library 'AD8232_Heart_Rate_Monitor'
    ; warning
    @(162.56 mm, 109.22 mm): Symbol U1 [AD8232]
[footprint_link_issues]: The current configuration does not include the footprint library 'AD8232_Heart_Rate_Monitor'
    ; warning
    @(167.64 mm, 203.20 mm): Symbol FRAME1 [FRAME-LETTER]
[footprint_link_issues]: The current configuration does not include the footprint library 'AD8232_Heart_Rate_Monitor'
    ; warning
    @(187.96 mm, 91.44 mm): Symbol R10 [RESISTOR0603-RES]
[footprint_link_issues]: The current configuration does not include the footprint library 'AD8232_Heart_Rate_Monitor'
    ; warning
    @(190.50 mm, 101.60 mm): Symbol C5 [CAP0603-CAP]
[footprint_link_issues]: The current configuration does not include the footprint library 'AD8232_Heart_Rate_Monitor'
    ; warning
    @(193.04 mm, 68.58 mm): Symbol R11 [RESISTOR0603-RES]
[footprint_link_issues]: The current configuration does not include the footprint library 'AD8232_Heart_Rate_Monitor'
    ; warning
    @(198.12 mm, 63.50 mm): Symbol R12 [RESISTOR0603-RES]
[footprint_link_issues]: The current configuration does not include the footprint library 'AD8232_Heart_Rate_Monitor'
    ; warning
    @(198.12 mm, 73.66 mm): Symbol R13 [RESISTOR0603-RES]
[footprint_link_issues]: The current configuration does not include the footprint library 'AD8232_Heart_Rate_Monitor'
    ; warning
    @(198.12 mm, 116.84 mm): Symbol R19 [0OHM1/10W5%(0603)]
[footprint_link_issues]: The current configuration does not include the footprint library 'AD8232_Heart_Rate_Monitor'
    ; warning
    @(198.12 mm, 132.08 mm): Symbol R20 [0OHM1/10W5%(0603)]
[footprint_link_issues]: The current configuration does not include the footprint library 'AD8232_Heart_Rate_Monitor'
    ; warning
    @(203.20 mm, 55.88 mm): Symbol C6 [CAP0805]
[footprint_link_issues]: The current configuration does not include the footprint library 'AD8232_Heart_Rate_Monitor'
    ; warning
    @(203.20 mm, 93.98 mm): Symbol R14 [RESISTOR0603-RES]
[footprint_link_issues]: The current configuration does not include the footprint library 'AD8232_Heart_Rate_Monitor'
    ; warning
    @(210.82 mm, 96.52 mm): Symbol C7 [CAP0603-CAP]
[footprint_link_issues]: The current configuration does not include the footprint library 'AD8232_Heart_Rate_Monitor'
    ; warning
    @(210.82 mm, 167.64 mm): Symbol LOGO2 [SFE_LOGO_NAME_FLAME.1_INCH]
[footprint_link_issues]: The current configuration does not include the footprint library 'AD8232_Heart_Rate_Monitor'
    ; warning
    @(256.54 mm, 172.72 mm): Symbol FID1 [FIDUCIAL1X2]
[footprint_link_issues]: The current configuration does not include the footprint library 'AD8232_Heart_Rate_Monitor'
    ; warning
    @(256.54 mm, 177.80 mm): Symbol FID2 [FIDUCIAL1X2]
[footprint_link_issues]: The current configuration does not include the footprint library 'AD8232_Heart_Rate_Monitor'
    ; warning
    @(261.62 mm, 172.72 mm): Symbol STANDOFF1 [STAND-OFF]
[footprint_link_issues]: The current configuration does not include the footprint library 'AD8232_Heart_Rate_Monitor'
    ; warning
    @(261.62 mm, 177.80 mm): Symbol STANDOFF2 [STAND-OFF]
[footprint_link_issues]: The current configuration does not include the footprint library 'AD8232_Heart_Rate_Monitor'
    ; warning
    @(266.70 mm, 172.72 mm): Symbol STANDOFF3 [STAND-OFF]
[footprint_link_issues]: The current configuration does not include the footprint library 'AD8232_Heart_Rate_Monitor'
    ; warning
    @(266.70 mm, 177.80 mm): Symbol STANDOFF4 [STAND-OFF]

 ** ERC messages: 61  Errors 18  Warnings 43

 ** Ignored checks:
    - Global label only appears once in the schematic
    - Four connection points are joined together
    - SPICE model issue
    - Assigned footprint doesn't match footprint filters

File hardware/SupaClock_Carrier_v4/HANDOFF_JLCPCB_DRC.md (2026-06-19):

# Handoff — Ajuste DRC y vías para JLCPCB (SupaClock Carrier v3)

## Contexto

- Proyecto: `hardware/SupaClock_Carrier_v3/SupaClock_Carrier.kicad_pro`
- PCB 2 capas, ya ruteada (XIAO ESP32-S3 SMD + filtro +BATT directo al pad 32, sin J15).
- DRC actual venía heredado de v2, configurado originalmente para una fresadora **LPKF** (de ahí los valores conservadores: `min_via_diameter=1.8 mm`, `min_track_width=0.4`, etc.).
- Ahora el destino de fabricación cambia a **JLCPCB**, que admite reglas mucho más finas. Queremos relajar el DRC a los mínimos de JLCPCB y reducir las vías para aprovechar la densidad disponible.

**Importante:** KiCad estaba abierto al cerrar la sesión anterior (lock file presente). Antes de tocar `.kicad_pro` o `.kicad_pcb`, confirmar que KiCad está cerrado:
```bash
pgrep -a kicad
ls hardware/SupaClock_Carrier_v3/~*.lck 2>/dev/null
```

## Estado actual (a cambiar)

Leído de `SupaClock_Carrier.kicad_pro` → `board.design_settings.rules`:

| Regla | Valor actual (LPKF) | Target JLCPCB |
|---|---|---|
| `min_clearance` | 0.3 | **0.127** |
| `min_track_width` | 0.4 | **0.127** |
| `min_via_diameter` | 1.8 | **0.45** |
| `min_via_annular_width` | 0.4 | **0.13** |
| `min_through_hole_diameter` | 0.8 | **0.3** |
| `min_hole_to_hole` | 0.8 | **0.5** |
| `min_hole_clearance` | 0.3 | **0.25** |
| `min_copper_edge_clearance` | 0.5 | **0.2** |
| `min_silk_clearance` | 0.15 | **0.15** (mantener) |
| `min_text_height` | 0.8 | **1.0** (JLCPCB pide ≥1 mm legible) |
| `min_text_thickness` | 0.15 | **0.15** |
| `min_microvia_diameter` | 0.5 | (no aplica, son blind/buried; no se usan) |

Net classes actuales (`net_settings.classes`):

| Clase | clearance | track_width | via_dia | via_drill |
|---|---|---|---|---|
| Default | 0.3 | 0.4 | 1.8 | 1.0 |
| Analog | 0.3 | 0.4 | 2.0 | 0.8 |
| Power | 0.3 | 0.8 | 2.0 | 0.8 |
| Power_HI | 0.3 | 1.0 | 2.0 | 0.8 |
| Signal_HF | 0.3 | 0.4 | 2.0 | 0.8 |

## Target JLCPCB (2 capas, 1 oz Cu, proceso estándar sin upcharges)

Valores tomados de la sección "PCB Capabilities" pública de JLCPCB (verificar siempre la versión vigente en jlcpcb.com antes de fabricar):

- Min trace / spacing: **0.127 mm** (5 mil). Usamos 0.15 mm como default para holgura.
- Min via: outer **0.45 mm** / drill **0.20 mm**. Estándar sin cargo: 0.6/0.3 mm.
- Min PTH drill: **0.3 mm**.
- Min annular ring: **0.13 mm** (5 mil).
- Min hole-to-hole: **0.5 mm** (placas <100 cm²).
- Min board edge clearance (copper a outline): **0.2 mm**.
- Min silk text: altura **1 mm**, ancho **0.15 mm**.

### Tamaños propuestos de vías y trazas por net class

| Clase | track_width | clearance | via_dia | via_drill | Uso |
|---|---|---|---|---|---|
| Default | 0.2 | 0.15 | 0.6 | 0.3 | Señales genéricas |
| Analog | 0.2 | 0.2 | 0.6 | 0.3 | ECG, MAX30205, MAX30102 |
| Power | 0.4 | 0.2 | 0.8 | 0.4 | +3V3 (corriente moderada) |
| Power_HI | 0.6 | 0.2 | 0.8 | 0.4 | +BATT, +5V/VBUS |
| Signal_HF | 0.2 | 0.2 | 0.6 | 0.3 | SPI LCD, USB D+/D- |

(Si después el ruteo no cabe con 0.2 mm en algún pasaje entre pads SMD del XIAO, bajar a 0.15 mm en esa pista puntualmente o usar via 0.45/0.2 mm en Default — sigue cumpliendo JLCPCB.)

## Cambios a aplicar

### 1. `SupaClock_Carrier.kicad_pro` (JSON)

Editar `board.design_settings.rules` con los valores target arriba. También editar cada entrada de `net_settings.classes` con la tabla de net classes propuesta. Snippet referencia de patch (no tomar literalmente — leer el JSON, mutarlo, re-escribir manteniendo el resto intacto):

```python
import json
p = 'hardware/SupaClock_Carrier_v3/SupaClock_Carrier.kicad_pro'
with open(p) as f: d = json.load(f)

rules = d['board']['design_settings']['rules']
rules.update({
    'min_clearance': 0.127,
    'min_track_width': 0.127,
    'min_via_diameter': 0.45,
    'min_via_annular_width': 0.13,
    'min_through_hole_diameter': 0.3,
    'min_hole_to_hole': 0.5,
    'min_hole_clearance': 0.25,
    'min_copper_edge_clearance': 0.2,
    'min_text_height': 1.0,
})

classes_target = {
    'Default':   {'clearance': 0.15, 'track_width': 0.2, 'via_diameter': 0.6, 'via_drill': 0.3},
    'Analog':    {'clearance': 0.2,  'track_width': 0.2, 'via_diameter': 0.6, 'via_drill': 0.3},
    'Power':     {'clearance': 0.2,  'track_width': 0.4, 'via_diameter': 0.8, 'via_drill': 0.4},
    'Power_HI':  {'clearance': 0.2,  'track_width': 0.6, 'via_diameter': 0.8, 'via_drill': 0.4},
    'Signal_HF': {'clearance': 0.2,  'track_width': 0.2, 'via_diameter': 0.6, 'via_drill': 0.3},
}
for c in d['net_settings']['classes']:
    if c['name'] in classes_target:
        c.update(classes_target[c['name']])

with open(p, 'w') as f: json.dump(d, f, indent=2)
```

### 2. `SupaClock_Carrier.kicad_pcb` (S-expressions)

KiCad replica las design rules en el header del `.kicad_pcb` (sección `(setup ...)`). Buscar y actualizar los mismos campos:

- `(pad_to_mask_clearance ...)` — dejar como está
- `(solder_mask_min_width ...)` — dejar como está
- En `(net_class "Default" ...)` aparecen `(clearance ...)`, `(trace_width ...)`, `(via_dia ...)`, `(via_drill ...)` — actualizar a los valores nuevos.

Si KiCad está cerrado al modificar el `.kicad_pro`, normalmente al reabrir el proyecto KiCad **propaga las design rules al PCB automáticamente** (te mostrará el "Board Setup → Constraints" actualizado). Pero los tamaños default de via/trace en `.kicad_pcb` no siempre se actualizan solos — abrir Board Setup → Net Classes y confirmar que se aplican; si no, editar el `.kicad_pcb` con los mismos valores que en `.kicad_pro`.

### 3. Resizing de vías existentes (acción manual en KiCad UI)

Cambiar las design rules **no encoge automáticamente** las vías ya colocadas (que están a 1.8/1.0 mm de la era LPKF). Para aprovechar el espacio:

1. En Pcbnew: `Edit → Find` → tipo "Via", o filtrar por `(via)` con el Inspector.
2. Mejor: **`Edit → Change Track Width`** o seleccionar todas las vias (clic derecho sobre una → Select → All Tracks/Vias in Net Class), luego `Properties` → asignar el tamaño nuevo de la net class.
3. Alternativa programática: regex sobre `.kicad_pcb` para reescribir `(via (at ...) (size 1.8) (drill 1.0) ...)` → `(size 0.6) (drill 0.3)` para Default. **Antes de hacerlo**: backup del .kicad_pcb. Y considerar que `Power`/`Power_HI` quieren via 0.8/0.4.

Esto último requiere identificar a qué net class pertenece cada via para asignar el tamaño correcto, lo cual está en `(net N "/nombre")` dentro de cada bloque `(via ...)`. Si es muy tedioso, dejar que el usuario lo haga visualmente en KiCad seleccionando por net class.

### 4. Recomendaciones adicionales JLCPCB

- **Tenting de vías**: JLCPCB hace tenting (vias cubiertas con soldermask) por defecto. Si tienes alguna via que quieres descubierta para test/medida, marcarla explícitamente en KiCad.
- **Fiducials**: si la PCB va a JLCPCB SMT Assembly, agregar 3 fiduciales no colineales (1 mm copper + 3 mm mask opening). No es necesario si solo es PCB sin assembly.
- **Nombre/revision en silkscreen**: incluir `SupaClock Carrier v3` y fecha/orden en F.Silk o B.Silk.
- **Outline**: revisar que `Edge.Cuts` sea un loop cerrado único (sin gaps ni overlaps), y que el silkscreen no salga del board edge (clearance ≥ 0.2 mm).
- **Drill table**: que KiCad genere drill files en formato Excellon 2:4 mm para JLCPCB.

## Verificación post-cambio

1. Cerrar KiCad si está abierto.
2. Aplicar cambios al `.kicad_pro` (y `.kicad_pcb` si hace falta).
3. Abrir el proyecto en KiCad. Si pide migración o muestra warnings, anotar y resolver antes de fabricar.
4. `Board Setup → Constraints`: confirmar valores de la tabla "Target JLCPCB" arriba.
5. `Board Setup → Net Classes`: confirmar tabla de net classes propuesta.
6. Reducir vías existentes (paso 3 arriba).
7. `Inspect → Design Rules Checker` → "Run DRC". No debe quedar ningún error de tipo:
   - Clearance violation
   - Track/via too small
   - Hole-to-hole too close
   - Copper-to-edge clearance
8. Exportar gerbers con JLCPCB profile estándar de KiCad (`File → Fabrication Outputs → Gerbers...`). Layers a incluir: `F.Cu B.Cu F.Paste B.Paste F.Silk B.Silk F.Mask B.Mask Edge.Cuts`. Drill: Excellon, formato decimal, plated/non-plated en un mismo archivo (JLCPCB acepta ambos).
9. Subir el zip a la calculadora de JLCPCB para que verifique automaticamente (esto cataloga warnings reales del fabricante).

## Archivos clave

- `hardware/SupaClock_Carrier_v3/SupaClock_Carrier.kicad_pro` — design rules + net classes (JSON)
- `hardware/SupaClock_Carrier_v3/SupaClock_Carrier.kicad_pcb` — vías y traces existentes + duplicado de design rules
- `hardware/SupaClock_Carrier_v3/footprints/SupaClock_Custom.pretty/` — footprints locales (incl. XIAO-ESP32-S3-SMD con pad 32=BAT+)
- `hardware/SupaClock_Carrier_v3/apply_lpkf_rules.py`, `fix_pads_lpkf.py` — scripts heredados, **NO ejecutar** (revertirían el cambio).

## Riesgos / cosas a vigilar

- Si reduces vías 1.8→0.6 mm en pads que tenían thermals dimensionados para vía grande, el cobre fundido del thermal puede verse afectado en simulación de fabricación. Verificar visualmente cada zona de power/GND tras el resize.
- Vías existentes pueden estar colocadas asumiendo holgura LPKF. Tras reducirlas y bajar el clearance, KiCad puede mostrar nuevos warnings de "track to via demasiado cerca" que antes no se veían. Re-rutear esos puntos puntuales.
- Si `apply_lpkf_rules.py` se corrió alguna vez sobre v3, los pads pudieron quedar oversized. Verificar tamaños de pads críticos (XIAO SMD pads 2.75×2.0 mm originales — confirmar que no se inflaron).
- El footprint local `XIAO-ESP32-S3-SMD.kicad_mod` tiene pads de programación bottom-side renumerados arbitrariamente (15→24, 16→26, 17→27, 18→28, 19→29, 20→30, 21→31, 22→34). Si el usuario decide después conectar uno de esos pads a una señal real, el mapeo señal-pad puede no corresponder con el silkscreen físico del módulo Seeed — verificar contra la datasheet antes de rutear.

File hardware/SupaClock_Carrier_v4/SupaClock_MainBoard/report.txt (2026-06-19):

Info: Processing symbol 'R_LEDA1:Resistor_SMD:R_0805_2012Metric_Pad1.20x1.40mm_HandSolder'.
Info: Processing symbol 'R3:Resistor_SMD:R_0805_2012Metric_Pad1.20x1.40mm_HandSolder'.
Info: Processing symbol 'R4:Resistor_SMD:R_0805_2012Metric_Pad1.20x1.40mm_HandSolder'.
Info: Processing symbol 'R_FG1:Resistor_SMD:R_0805_2012Metric_Pad1.20x1.40mm_HandSolder'.
Info: Processing symbol 'R_FG2:Resistor_SMD:R_0805_2012Metric_Pad1.20x1.40mm_HandSolder'.
Info: Processing symbol 'R_FG_ALT1:Resistor_SMD:R_0805_2012Metric_Pad1.20x1.40mm_HandSolder'.
Info: Processing symbol 'R_FG_QST1:Resistor_SMD:R_0805_2012Metric_Pad1.20x1.40mm_HandSolder'.
Info: Processing symbol 'R_GATE1:Resistor_SMD:R_0805_2012Metric_Pad1.20x1.40mm_HandSolder'.
Info: Processing symbol 'R_IM1:Resistor_SMD:R_0805_2012Metric_Pad1.20x1.40mm_HandSolder'.
Info: Processing symbol 'C4:Capacitor_SMD:C_0805_2012Metric_Pad1.18x1.45mm_HandSolder'.
Info: Processing symbol 'R_RD1:Resistor_SMD:R_0805_2012Metric_Pad1.20x1.40mm_HandSolder'.
Info: Processing symbol 'R_RST1:Resistor_SMD:R_0805_2012Metric_Pad1.20x1.40mm_HandSolder'.
Info: Processing symbol 'SW1:SupaClock_Custom:SW_Tactile_Side_3.5x7.8mm'.
Info: Processing symbol 'SW2:SupaClock_Custom:SW_Tactile_Side_3.5x7.8mm'.
Info: Processing symbol 'U1:Seeed_Studio_XIAO_Footprints:XIAO-ESP32-S3-SMD'.
Info: Processing symbol 'U2:SupaClock_Custom:MAX17048_WDFN8_HandSolder'.
Info: Processing symbol 'C2:Capacitor_SMD:C_0805_2012Metric_Pad1.18x1.45mm_HandSolder'.
Info: Processing symbol 'R1:Resistor_SMD:R_0805_2012Metric_Pad1.20x1.40mm_HandSolder'.
Info: Processing symbol 'C5:Capacitor_SMD:C_0805_2012Metric_Pad1.18x1.45mm_HandSolder'.
Info: Processing symbol 'C_DISP1:Capacitor_SMD:C_0805_2012Metric_Pad1.18x1.45mm_HandSolder'.
Info: Processing symbol 'C_DISP2:Capacitor_SMD:C_0805_2012Metric_Pad1.18x1.45mm_HandSolder'.
Info: Processing symbol 'C_FG1:Capacitor_SMD:C_0805_2012Metric_Pad1.18x1.45mm_HandSolder'.
Info: Processing symbol 'C_FG2:Capacitor_SMD:C_0805_2012Metric_Pad1.18x1.45mm_HandSolder'.
Info: Processing symbol 'C_RST1:Capacitor_SMD:C_0805_2012Metric_Pad1.18x1.45mm_HandSolder'.
Info: Processing symbol 'J_BAT1:Connector_JST:JST_PH_B2B-PH-K_1x02_P2.00mm_Vertical'.
Info: Processing symbol 'J_CONN_SENSOR1:Connector_JST:JST_PH_B6B-PH-K_1x06_P2.00mm_Vertical'.
Info: Processing symbol 'J_FPC1:Connector_FFC-FPC:Hirose_FH12-24S-0.5SH_1x24-1MP_P0.50mm_Horizontal'.
Info: Processing symbol 'R2:Resistor_SMD:R_0805_2012Metric_Pad1.20x1.40mm_HandSolder'.
Info: Processing symbol 'J_IMU1:Connector_PinHeader_2.54mm:PinHeader_1x07_P2.54mm_Vertical'.
Info: Processing symbol 'Q1:Package_TO_SOT_SMD:SOT-23_Handsoldering'.
Connected U1 pin 14 to unconnected-(U1-VBUS-Pad14).
Connected U1 pin 5 to I2C_SDA.
Connected U1 pin 7 to BTN_NEXT.
Add net unconnected-(U1-VBUS-Pad14).
Connected U1 pin 10 to BTN_SELECT.
Connected U1 pin 13 to GND.
Connected U1 pin 3 to BLK_PWM.
Add net unconnected-(U1-GPIO40_MTDO-Pad25).
Connected U1 pin 25 to unconnected-(U1-GPIO40_MTDO-Pad25).
Connected U1 pin 1 to ECG_OUT.
Connected U1 pin 4 to SPI_DC.
Connected U1 pin 8 to SPI_CS.
Updated U1 unit metadata.
Removed unused footprint H4.
Removed unused footprint H1.
Removed unused footprint H3.
Removed unused footprint H2.
Connected U1 pin 24 to unconnected-(U1-GPIO41_MTDI-Pad24).
Updated U1 symbol association from  to /db6f3556-5f5e-4a55-aaf6-6296fc445b68.
Updated U1 sheetname to '/'.
Updated U1 sheetfile to 'SupaClock_MainBoard.kicad_sch'.
Connected U1 pin 2 to ECG_SDN.
Connected U1 pin 11 to SPI_MOSI.
Changed U1 value from Val** to XIAO-ESP32-S3.
Changed REF** reference designator to U1.
Connected U1 pin 9 to SPI_SCK.
Connected U1 pin 12 to +3V3.
Connected U1 pin 6 to I2C_SCL.
Added U1 (footprint 'Seeed_Studio_XIAO_Footprints:XIAO-ESP32-S3-SMD').
Add net unconnected-(U1-GPIO41_MTDI-Pad24).
Warning: No net found for component J_FPC1 pad MP (no pin MP in symbol).
Warning: No net found for component J_FPC1 pad MP (no pin MP in symbol).
Warning: No net found for component U1 pad 16 (no pin 16 in symbol).
Warning: No net found for component U1 pad 17 (no pin 17 in symbol).
Warning: No net found for component U1 pad 19 (no pin 19 in symbol).
Warning: No net found for component U1 pad 21 (no pin 21 in symbol).
Warning: No net found for component U1 pad 23 (no pin 23 in symbol).
Warning: No net found for component U1 pad 20 (no pin 20 in symbol).
Warning: No net found for component U1 pad 18 (no pin 18 in symbol).
Warning: No net found for component U1 pad 15 (no pin 15 in symbol).
Warning: No net found for component U1 pad 22 (no pin 22 in symbol).
Error: U1 pad 32 not found in Seeed_Studio_XIAO_Footprints:XIAO-ESP32-S3-SMD.
Error: U1 pad 33 not found in Seeed_Studio_XIAO_Footprints:XIAO-ESP32-S3-SMD.
Error: U1 pad 26 not found in Seeed_Studio_XIAO_Footprints:XIAO-ESP32-S3-SMD.
Error: U1 pad 27 not found in Seeed_Studio_XIAO_Footprints:XIAO-ESP32-S3-SMD.
Error: U1 pad 30 not found in Seeed_Studio_XIAO_Footprints:XIAO-ESP32-S3-SMD.
Error: U1 pad 31 not found in Seeed_Studio_XIAO_Footprints:XIAO-ESP32-S3-SMD.
Error: U1 pad 29 not found in Seeed_Studio_XIAO_Footprints:XIAO-ESP32-S3-SMD.
Error: U1 pad 28 not found in Seeed_Studio_XIAO_Footprints:XIAO-ESP32-S3-SMD.
Error: U1 pad 34 not found in Seeed_Studio_XIAO_Footprints:XIAO-ESP32-S3-SMD.

Info: Total warnings: 11, errors: 9.

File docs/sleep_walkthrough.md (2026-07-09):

# Walkthrough: Mejoras de Sueño y Robustez del Sistema (Sleep / Deep Sleep Fixes)

Hemos implementado con éxito todas las fases propuestas en el plan de diseño para optimizar la gestión de energía y la fiabilidad del hardware en **SupaClock**. El firmware compila limpiamente sin advertencias ni errores.

---

## 1. Cambios Implementados

### 1.1. Driver de Pantalla Táctil (`cst816s_driver`)
*   **Archivos Modificados**: [cst816s.h](file:///home/articunot/Documents/PlatformIO/Projects/SupaClock/lib/cst816s_driver/cst816s.h) y [cst816s.c](file:///home/articunot/Documents/PlatformIO/Projects/SupaClock/lib/cst816s_driver/cst816s.c)
*   **Cambio**: Añadimos la función `cst816s_shutdown()` que fuerza a la línea de hardware Reset (`s_rst_pin`) a nivel lógico `0` de manera sostenida. Esto pone al chip táctil en su estado físico de apagado (LPM profundo) antes de que el ESP32-S3 se duerma.

### 1.2. Driver de Botones (`gpio_buttons`)
*   **Archivos Modificados**: [gpio_buttons.c](file:///home/articunot/Documents/PlatformIO/Projects/SupaClock/lib/gpio_buttons/gpio_buttons.c)
*   **Cambio**: 
    *   Incluimos `<esp_system.h>` para tener acceso a las funciones de reinicio de la CPU.
    *   En la tarea del temporizador de debounce periódico de 10ms (`btn_timer_cb`), agregamos una guarda de acumulación de tiempo. Si la lectura física del botón SELECT detecta que está presionado de forma continua por **5000 ms (5 segundos)**, se ejecuta una llamada inmediata de pánico a `esp_restart()`, reiniciando el dispositivo al instante ante cualquier cuelgue del hilo de interfaz gráfica (UI thread).

### 1.3. Aplicación Principal (`supaclock_app`)
*   **Archivos Modificados**: [supaclock_app.c](file:///home/articunot/Documents/PlatformIO/Projects/SupaClock/lib/supaclock_app/supaclock_app.c)
*   **Cambios**:
    1.  **Secuencia de Apagado Ordenada en `on_power_off()`**:
        *   Primero apagamos el Backlight y dormimos la pantalla GC9A01 con `gc9a01_set_brightness(0)`.
        *   Fuerza el apagado del touch CST816S con `cst816s_shutdown()`.
        *   Fuerza el apagado del chip analógico del ECG con `ad8232_power_down()`.
        *   Inserta un retardo de `200ms` para estabilizar las líneas físicas de alimentación del circuito.
    2.  **Corrección de Flotación de Wake-Up (Solución al Auto-Reinicio de los 5 segundos)**:
        *   Configuramos explícitamente el pin de wake-up `BTN_SELECT_PIN` (GPIO 8) como un pin del RTC: `rtc_gpio_init`, `rtc_gpio_set_direction` y activamos explícitamente el pull-up interno retenido (`rtc_gpio_pullup_en`, `rtc_gpio_pulldown_dis`).
        *   Configuramos la unidad de potencia (`esp_sleep_pd_config`) para mantener energizado el dominio periférico del RTC (`ESP_PD_DOMAIN_RTC_PERIPH`) durante el deep sleep. Esto mantiene activo el pull-up de 3.3V en el pin 8, impidiendo que la señal flote hacia 0V y cause falsos encendidos cíclicos.
    3.  **Encendido Seguro por Pulsación Larga ("Hold to Turn On" 1.5s)**:
        *   Al arrancar en `supaclock_app_run()`, comprobamos si el motivo del reinicio fue un despertar de deep sleep (`ESP_SLEEP_WAKEUP_EXT1`).
        *   Si es así, entramos en un bucle temporal de 1500ms donde monitorizamos el estado físico del botón SELECT.
        *   Si el usuario suelta el botón antes de que transcurran los 1.5 segundos, el reloj asume que fue un toque accidental en el bolsillo y llama de inmediato a `on_power_off()` para volverse a dormir al instante sin llegar a encender la pantalla.

---

## 2. Resultados de Validación y Compilación
*   **Estado de Compilación**: **Éxito absoluto** (`pio run -e main_app`).
*   **Uso de Recursos del ESP32-S3**:
    *   **SRAM (RAM)**: **47.5%** (155,644 bytes usados de 327,680 bytes).
    *   **Flash (ROM)**: **37.3%** (1,172,853 bytes usados de 3,145,728 bytes).

Las modificaciones a los drivers son completamente seguras y no añaden ningún tipo de retraso o sobrecarga a los subprocesos de muestreo del HAR o NimBLE.

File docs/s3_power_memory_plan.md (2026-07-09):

# Migración a XIAO ESP32-S3 — Plan de Potencia, Memoria y CNN-1D HAR

> Documento vivo. Última revisión: 2026-05-23.
> Aplica al carrier `hardware/SupaClock_Carrier/` (v1, header-only).

## 1. Por qué migramos

El **ESP32-C3 SuperMini** nos limitó en tres frentes:

| Limitante (C3) | Impacto en SupaClock |
|---|---|
| Un solo core RISC-V | LVGL + BLE + I2C scan + AD8232 DMA chocaron por scheduling |
| 400 kB SRAM, sin PSRAM | LVGL doble buffer + modelo CNN ≥ 100 kB no caben |
| Sin SIMD para INT8 | El HAR INT8 cuesta ~5× más que en S3 |
| ADC con SAR único compartido | El AD8232 DMA paralelo a WiFi/BLE introducía glitches |

El **XIAO ESP32-S3** resuelve los cuatro:
- **Dual core Xtensa LX7 @ 240 MHz** (cada uno con FPU + SIMD vectorial).
- **8 MB Octal PSRAM** disponible para LVGL, modelo y arenas grandes.
- **ESP-NN** kernels TFLite-Micro acelerados (PIE 128-bit).
- **ADC1 separado** + **ULP-RISC-V** (futuro: muestrear ECG en sleep).

## 2. Asignación de cores

| Core | Tareas | Justificación |
|---|---|---|
| **Core 0** (PRO) | NimBLE host, LVGL, I2C slow sensors (temp/fuel), GUI input | Tareas latency-sensitive de UI y radio |
| **Core 1** (APP) | HAR CNN-1D, AD8232 DMA callback, MAX30102 FIFO drain | Tareas con bursts predecibles, no quieren ser interrumpidas por BLE TX |

Pin de la task del HAR:
```c
xTaskCreatePinnedToCore(har_task, "har_task", 4096, NULL, 4, NULL, /*core=*/ 1);
```

## 3. Asignación de memoria

| Buffer | Tamaño | Memoria | Razón |
|---|---|---|---|
| LVGL frame buffer × 2 | 240·280·2 B · 2 ≈ **268 kB** | **PSRAM** | No cabe en SRAM, se accede secuencialmente vía DMA bounce |
| LVGL bounce buffer DMA | ~16 kB | **SRAM interna** | Requerido por SPI DMA (PSRAM no es DMA-capable directa) |
| Ring buffer HAR (200×6×2) | 2.4 kB | **SRAM interna** | Accedido en hot path por la task de inferencia |
| Tensor arena TFLite | 24 kB (configurable) | **PSRAM** (`HAR_TENSOR_ARENA_IN_PSRAM=1`) | Pesa, vive durante toda la app |
| Modelo `.tflite` blob | 30–60 kB | **Flash** (rodata) | Const, mapeado por XIP |
| AD8232 DMA buffer | 1 kB × 4 | **SRAM interna** | Latencia crítica |
| BLE TX queues | ~8 kB | **SRAM interna** (NimBLE default) | NimBLE no soporta PSRAM para sus colas |
| Heap general | resto | **PSRAM** vía `CONFIG_SPIRAM_USE_MALLOC=y` | `malloc()` grande → PSRAM, chico → SRAM |

`sdkconfig.defaults` ya tiene:
```
CONFIG_SPIRAM_MALLOC_ALWAYSINTERNAL=16384   # <16 kB → SRAM
CONFIG_SPIRAM_MALLOC_RESERVE_INTERNAL=32768 # reservar 32 kB para ISR / DMA
```

### 3.1 Mediciones Reales de Compilación (Fase 6 Touch UI)

Tras la implementación de toda la arquitectura del router táctil, las aplicaciones nativas completas y la integración de las fuentes e iconos custom (FontAwesome solid/brands y rango de acentos de español), las métricas estáticas del firmware son:

*   **SRAM Estática (RAM)**: **47.1%** (154,500 bytes usados de 327,680 bytes).
*   **Flash (Programa)**: **34.6%** (1,087,377 bytes usados de 3,145,728 bytes).

Las fuentes agregadas se mapean en Flash/XIP por lo que consumen 0 bytes de RAM adicionales, garantizando que más del 50% de la SRAM quede disponible para heap dinámico (buffers DMA, colas NimBLE, etc.). Esto valida con creces la holgura del ESP32-S3.

## 4. Plan de bajo consumo

### 4.1 DVFS + Light-Sleep automático

```c
esp_pm_config_t pm = {
    .max_freq_mhz = 240,   /* HAR / DMA bursts */
    .min_freq_mhz = 80,    /* idle típico       */
    .light_sleep_enable = true,
};
esp_pm_configure(&pm);
```

Con `CONFIG_FREERTOS_USE_TICKLESS_IDLE=y`, el SoC entra en light-sleep cuando todas las tasks duermen. BLE NimBLE coopera vía `CONFIG_BT_CTRL_MODEM_SLEEP_MODE_1=y`.

### 4.2 Cadencias por modo (de `power_modes.h`)

| Sensor | SPORT | NORMAL | SAVER |
|---|---|---|---|
| BMI160 ODR | 100 Hz | 100 Hz | 50 Hz (LP) |
| HAR inferencia | 1 Hz | 1 Hz | gated por varianza |
| MAX30102 | continuo | spot 30 s | spot 5 min |
| MAX30205 | 5 s | 30 s | 5 min |
| MAX17048 | 10 s | 60 s | 5 min |
| LVGL refresh | 30 fps | 15 fps | 5 fps + dimmed |

### 4.3 Gating del CNN
- En `POWER_MODE_SAVER`, el HAR mide varianza de |a| sobre 1 s; sólo invoca el intérprete si supera un umbral mínimo. El detector de caídas sigue corriendo (es trivial).
- En reposo prolongado (>5 min sin actividad), `har_cnn1d_pause()` apaga la task completa.

### 4.4 Periféricos en shutdown
- AD8232: `ad8232_power_down()` por defecto (SDN low), sólo encender al entrar a la pantalla ECG.
- MAX30102: SHDN entre mediciones spot (`hrm_shdn_between=true`).
- Backlight LCD: PWM duty 0 cuando display está auto-off; el ST7789 entra en SLPIN.

### 4.5 Estimación de corriente (target)
| Estado | Corriente promedio | Notas |
|---|---|---|
| Display on + HAR + BLE conn. | ~85 mA | LCD domina (50 mA backlight 60 %) |
| Display off + HAR + BLE adv. | ~12 mA | CPU mayormente dormida |
| SAVER, screen off, HAR gated | ~3 mA | Sólo BMI160 LP @50 Hz + RTC |

Bate de 250 mAh → ~80 h en SAVER, ~20 h en NORMAL display-off, ~3 h pantalla 100 %.

## 5. CNN-1D HAR — arquitectura y plan de entrenamiento

### 5.1 Entrada y salida
- 6 canales (ax, ay, az, gx, gy, gz) raw int16 del BMI160.
- Ventana 2 s @ 100 Hz = 200 muestras. Hop 1 s.
- Clases:
  - `RESTING` / `WALKING` / `RUNNING` (softmax de 3 vías)
  - Evento `FALL` reportado por separado (head heurístico/binario)

### 5.2 Por qué Fall en cabeza separada
Las caídas son sub-segundo, raras, y mezclarlas en un softmax desestabiliza las 3 clases base. El detector heurístico (free-fall → impacto → quietud) ya implementado tiene precisión >95 % en literatura UCI con costo ~5 instrucciones por muestra. Más adelante puede reemplazarse por una mini-CNN binaria que comparta el backbone.

### 5.3 Topología propuesta (≈ 40 kB INT8)
```
Input (200, 6)
 └─ Conv1D(16, k=5, stride=2)  + ReLU + BN     → (100, 16)
 └─ Conv1D(32, k=5, stride=2)  + ReLU + BN     → ( 50, 32)
 └─ Conv1D(64, k=3, stride=2)  + ReLU + BN     → ( 25, 64)
 └─ GlobalAveragePooling1D                       → (   64)
 └─ Dense(3, softmax)                            → (    3)
```
Cuantización post-entrenamiento a INT8 (representative dataset = capturas BLE reales del `test_imu` corriendo en el dispositivo).

### 5.4 Pipeline de entrenamiento (a crear en `tools/har/`)
1. **Captura** — `test_imu` + app Flutter logean a CSV etiquetado por clase.
2. **Preprocesado** — `numpy` ventaneo deslizante, balanceo de clases, splits estratificados.
3. **Train** — `tensorflow==2.16`, Keras Sequential; 30–50 épocas, augmentation por jitter + scaling.
4. **Quant** — `tf.lite.TFLiteConverter.from_keras_model` con `optimizations=[Optimizations.DEFAULT]` + representative dataset → `.tflite`.
5. **Embed** — `xxd -i har_model.tflite > lib/har_cnn1d/har_model.cc` (genera `har_model_tflite[]` y `_len`).
6. **Validate** — `test_har` en el dispositivo + matriz de confusión BLE.

### 5.5 Integración TFLite-Micro
Componente managed: `idf.py add-dependency "espressif/esp-tflite-micro"`. Luego descomentar los `#include` y la función `har_runner_run` en `lib/har_cnn1d/har_model_runner.cpp`. El intérprete corre con `MicroMutableOpResolver` declarando sólo los ops necesarios: `Conv2D`, `FullyConnected`, `Softmax`, `Reshape`, `Quantize`, `Dequantize`. Esto reduce el footprint del kernel registry de 80 kB → 12 kB.

## 6. Checklist de lo que falta tras esta migración

- [ ] Probar `pio run -e test_imu` en el carrier real.
- [ ] Capturar dataset etiquetado (mínimo 30 min/clase) con el dispositivo puesto en muñeca.
- [ ] Entrenar y exportar `har_model.tflite`.
- [ ] Añadir `esp-tflite-micro` como managed component y descomentar el runner.
- [ ] Cablear UI: una tarjeta LVGL "Activity" con la clase actual + icono.
- [ ] Cablear evento FALL → notificación BLE custom + banner rojo en LCD + log NVS.
- [ ] Verificar `esp_pm_lock` en las tasks de DMA (AD8232) para que no bajen el clock durante una captura.

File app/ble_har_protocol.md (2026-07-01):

# SupaClock — Protocolo BLE y Pipeline HAR (ESP32-S3)

> Documento de referencia para el equipo de la aplicación Flutter.  
> Describe el flujo completo desde la captura inercial en el firmware hasta la
> interpretación del estado de actividad en la app, incluyendo todos los formatos
> de byte exactos del protocolo BLE.  
> **Cualquier cambio en la app que toque UUIDs, offsets o valores enumerados
> debe verificarse contra este documento para evitar regresiones.**

---

## Índice

1. [Visión general del sistema](#1-visión-general-del-sistema)
2. [Pipeline HAR en el firmware](#2-pipeline-har-en-el-firmware)
   - 2.1 Captura IMU (BMI160)
   - 2.2 Ring buffer y ventana de inferencia
   - 2.3 Modelo TFLite Micro (ResNet-1D + LSTM)
   - 2.4 Filtro EMA y consolidación de estado
   - 2.5 Callback y publicación BLE
3. [Protocolo BLE](#3-protocolo-ble)
   - 3.1 Servicio y características
   - 3.2 Característica 0xFF01 — IMU raw
   - 3.3 Característica 0xFF02 — Telemetría agregada TLV
   - 3.4 Característica 0xFF03 — Streaming ECG
   - 3.5 Característica 0xFF04 — Comandos (escritura)
4. [Formato de los records TLV](#4-formato-de-los-records-tlv)
   - 4.1 Header del paquete agregado
   - 4.2 TLV 0x01 — Frecuencia cardíaca (HR)
   - 4.3 TLV 0x02 — Saturación de oxígeno (SpO2)
   - 4.4 TLV 0x03 — Temperatura
   - 4.5 TLV 0x04 — Batería
   - 4.6 TLV 0x05 — Pasos acumulados
   - 4.7 TLV 0x06 — Cambio de modo de energía
   - 4.8 TLV 0x07 — Resultado SPOT (HR+SpO2 on-demand)
   - 4.9 TLV 0x08 — Estado HAR (actividad)
5. [Cadencias de publicación por modo](#5-cadencias-de-publicación-por-modo)
6. [Enumeraciones de referencia](#6-enumeraciones-de-referencia)
7. [Implementación en Flutter (BleService)](#7-implementación-en-flutter-bleservice)
8. [Contratos de no-rotura](#8-contratos-de-no-rotura)

---

## 1. Visión general del sistema

```
┌─────────────────────────────── ESP32-S3 ───────────────────────────────┐
│                                                                        │
│  BMI160 (I2C)                                                          │
│     │ ax,ay,az,gx,gy,gz  int16 @ 100 Hz                               │
│     ▼                                                                  │
│  imu_task (core 0)──────────────────────────────► step_algo           │
│     │                                                 │ steps_sw       │
│     │ int16[6]  @ modo                               ▼                │
│     ├─► ble_telemetry_send_imu()  ──► 0xFF01 (notify directo)         │
│     └─► app_state (shared_sensor_data_t)                              │
│                                                                        │
│  har_task (core 1, prio 4)                                             │
│     │ Promedia 2 muestras físicas → 50 Hz efectivos                   │
│     │ Ring buffer circular 200×6 int16 (= 4.0 s @ 50 Hz)             │
│     │ Warmup: espera 200 pushes antes de inferir                       │
│     │ Inferencia cada 100 pushes (= 2 s, overlap 50%)                 │
│     │                                                                  │
│     ▼ ResNet-1D + LSTM INT8 TFLite Micro (624 KB en PSRAM)            │
│     │ Arena 384 KB en SRAM interna                                     │
│     │ Probs[4]: RESTING / WALKING / RUNNING / STAIRS                  │
│     │                                                                  │
│     ▼ EMA α=0.5 sobre probs + consolidación 3 consecutivas            │
│     │                                                                  │
│     └─► on_har_result() callback                                       │
│              │                                                         │
│              ├─► app_state.har_state (uint8)                           │
│              └─► ble_tx_push(0x08, state, 1B) ──► 0xFF02 (TLV flush) │
│                                                                        │
│  hrm_task / system_task / ecg_task                                     │
│     └─► ble_tx_push(tipo, datos) ──► buffer agregado                  │
│                                                                        │
│  ble_tx_task                                                           │
│     └─► ble_tx_flush() periódico ──► 0xFF02 notify                    │
│                                                                        │
└────────────────────────────────────────────────────────────────────────┘
                          ▼ BLE (NimBLE / GATT)
┌──────────────── Flutter App (BleService) ──────────────────────────────┐
│  _onImuData()   ← 0xFF01                                              │
│  _onAggData()   ← 0xFF02  (parsea header + TLV loop)                  │
│  _onEcgData()   ← 0xFF03                                              │
│  sendCommand()  → 0xFF04                                               │
│                                                                        │
│  SupaClockTelemetry.harState (int 0-3) → UI                           │
└────────────────────────────────────────────────────────────────────────┘
```

---

## 2. Pipeline HAR en el firmware

### 2.1 Captura IMU (BMI160)

- **Sensor**: BMI160 vía I2C, rango de fábrica ±2 g (acelerómetro) y ±250 dps (giroscopio).
- **Resolución**: int16, rango completo ±32 768 LSB (a plena escala).
- **Task**: `imu_task` (core 0) muestrea a `p->imu_poll_ms` según el modo de energía activo:
  - SPORT → 20 ms (50 Hz físicos)
  - NORMAL → 40 ms (25 Hz físicos)
  - SAVER → 80 ms (12.5 Hz físicos)

> **Nota para la app**: la característica 0xFF01 refleja esta cadencia. En modo SAVER
> habrá notificaciones más espaciadas. No asumir 50 Hz fijo.

El `imu_task` escribe `imu_raw[6]` en `app_state` y, si `app_state_imu_tx_enabled()` es true,
llama a `ble_telemetry_send_imu()` (envío directo, sin buffer agregado).

---

### 2.2 Ring buffer y ventana de inferencia

El `har_task` corre en core 1 como **consumidor de inferencia**. **No lee el
sensor**: `imu_task` (core 0) drena el FIFO del BMI160 a **50 Hz** y alimenta el
ring del HAR con cada muestra vía `har_cnn1d_push_sample()`. Así hay un único
lector del bus I2C (sin contención ni FIFO overflow). El modelo es 50 Hz nativo.

```
BMI160 FIFO @50 Hz → imu_task → har_cnn1d_push_sample() → ring buffer (50 Hz)
                                                          → notify → har_task (infiere)
```

> **Nota:** el diseño anterior leía el BMI160 a 100 Hz desde la har_task y
> promediaba 2→1; se reemplazó por este feed único de 50 Hz (2026-06-25).

**Ring buffer** `s_ring[200][6]` (int16, 2.4 KB en SRAM interna):
- Tamaño: `HAR_WINDOW_SIZE = 200` muestras × 6 canales.
- Ventana temporal: 200 / 50 Hz = **4.0 segundos**.
- Escritura circular: `s_write_idx` apunta siempre a la próxima posición a escribir.

**Warmup de arranque**: la primera inferencia se ejecuta solo después de que el
ring buffer esté completamente lleno con datos reales (`s_total_ring_pushes >= 200`),
lo que ocurre a los **4 s desde el boot**. Antes de ese tiempo, el HAR no emite
ningún resultado. La app **no debe asumir** que recibirá un TLV 0x08 inmediatamente
tras conectarse.

**Cadencia de inferencia**:
- Hop size: `HAR_HOP_SIZE = 100` muestras = **2 s de datos nuevos**.
- Overlap: 50 % (las últimas 100 muestras de la ventana anterior se reutilizan).
- Resultado: **1 inferencia cada 2 s**, comenzando a los 4 s del boot.

**Construcción de la ventana**: cuando se dispara la inferencia con `s_write_idx = W`,
la ventana cronológica se construye como:
```
posición 0  → s_ring[(W + 0)   % 200]  ← muestra más antigua
posición 1  → s_ring[(W + 1)   % 200]
...
posición 199→ s_ring[(W + 199) % 200]  ← muestra más reciente
```

---

### 2.3 Modelo TFLite Micro (ResNet-1D + LSTM)

**Arquitectura** (`tools/train_har_cnn.py`):

```
Input: (1, 200, 6)  ← [batch, tiempo, canales: ax,ay,az,gx,gy,gz]
  │
  ├─ Conv1D(32, k=5, relu) → MaxPool1D(2)      → (1, 100, 32)
  │
  ├─ Bloque Residual 1:
  │    shortcut: Conv1D(64, k=1)
  │    main: Conv1D(64,k=3) → BN → ReLU → Conv1D(64,k=3) → BN
  │    add(main, shortcut) → ReLU → MaxPool1D(2)           → (1, 50, 64)
  │
  ├─ Bloque Residual 2:
  │    shortcut: Conv1D(128, k=1)
  │    main: Conv1D(128,k=3) → BN → ReLU → Conv1D(128,k=3) → BN
  │    add(main, shortcut) → ReLU → MaxPool1D(2)            → (1, 25, 128)
  │
  ├─ Bloque Residual 3:
  │    shortcut: Conv1D(256, k=1)
  │    main: Conv1D(256,k=3) → BN → ReLU → Conv1D(256,k=3) → BN
  │    add(main, shortcut) → ReLU → MaxPool1D(2)            → (1, 12, 256)
  │
  ├─ LSTM(64, unroll=True, return_sequences=False)           → (1, 64)
  ├─ Dense(64, relu)
  ├─ Dropout(0.3)  [solo en entrenamiento]
  └─ Dense(4, softmax)                                       → (1, 4)
```

**Cuantización**: INT8 completo (`converter.inference_input_type = tf.int8`,
`converter.inference_output_type = tf.int8`). Los parámetros `scale` y `zero_point`
del tensor de entrada y salida se imprimen al boot:
```
TFLite Init: input type=9, scale=X, zp=Y; output type=9, scale=A, zp=B
```

**Normalización de entrada** (`har_model_runner.cpp`): los int16 del ring se
normalizan a `[-1.0, 1.0]` dividiendo por `32768.0f` antes de aplicar la
cuantización INT8:
```c
float ax = (float)window[i][0] / 32768.0f;  // → [-1.0, 1.0]
// luego: q = ax / scale + zero_point
```

**Operadores TFLite registrados** en el resolver (`har_model_runner.cpp`):

| Operador | Uso en el modelo |
|---|---|
| `CONV_2D` | Conv1D de todas las capas (TFLite mapea Conv1D → Conv2D) |
| `MAX_POOL_2D` | MaxPooling1D entre bloques |
| `MEAN` | promedio global si se usa GAP |
| `FULLY_CONNECTED` | capas Dense |
| `SOFTMAX` | capa de salida |
| `RESHAPE` | ajuste de dimensiones |
| `QUANTIZE` / `DEQUANTIZE` | bordes del grafo INT8 |
| `EXPAND_DIMS` | adaptación de forma |
| `ADD` | skip-connections de los bloques residuales |
| `RELU` | **ReLU standalone después de cada ADD residual** |
| `LOGISTIC` / `TANH` | puertas de la LSTM (sigmoid/tanh) |
| `FILL`, `MUL`, `PACK`, `SHAPE`, `SPLIT`, `STRIDED_SLICE`, `TRANSPOSE`, `UNPACK` | LSTM desenrollada |

> **Crítico**: Si se actualiza el modelo (reentrenamiento) y la nueva arquitectura
> introduce operadores no listados aquí, `AllocateTensors()` fallará silenciosamente
> (el firmware cae a estado `RESTING` por seguridad). Verificar con los logs de boot
> que `model_ok = true`.

**Memoria**:
- Modelo `.tflite`: ~624 KB copiado a **PSRAM** al init (`heap_caps_malloc MALLOC_CAP_SPIRAM`).
- Tensor Arena: **384 KB** en **SRAM interna** (`heap_caps_aligned_alloc MALLOC_CAP_INTERNAL`).
  Si no hay SRAM suficiente, fallback a PSRAM (log `LOGW: intentando en PSRAM`).

---

### 2.4 Filtro EMA y consolidación de estado

Las probabilidades brutas `probs[4]` del modelo pasan por dos capas de filtrado
antes de generar el estado final:

**Capa 1 — EMA (Exponential Moving Average)**:
```c
// α = 0.5, inicializado en { 1.0, 0.0, 0.0, 0.0 }  (RESTING dominante al boot)
s_probs_ema[i] = 0.5f * probs[i] + 0.5f * s_probs_ema[i];
```

Con α = 0.5, si el modelo predice `WALKING=0.8` consistentemente:
- Ventana 1 tras boot: EMA_rest ≈ 0.75,  EMA_walk ≈ 0.25
- Ventana 2: EMA_rest ≈ 0.55,  EMA_walk ≈ 0.45
- Ventana 3: EMA_rest ≈ 0.35,  EMA_walk ≈ 0.60 ← argmax flipa a WALKING
- Ventana 4+: converge a WALKING

Tiempo desde arranque hasta que el EMA reporta WALKING por primera vez:
≈ **3 ventanas × 2 s = ~10 s** (incluyendo el warmup de 4 s).

**Capa 2 — Consecutivas (histeresis)**:
```c
// 3 ventanas consecutivas del mismo argmax(EMA) → consolida el estado
if (s_consecutive_count >= 3) s_consolidated_state = s_candidate_state;
```

**Latencia total mínima desde el boot hasta detectar WALKING**:
- Warmup buffer: 4 s
- Primera inferencia donde EMA flipa: ~+6 s
- 3 consecutivas: ~+6 s
- **Total mínimo: ~16 s** desde que el usuario empieza a caminar con el reloj encendido.

Tras una transición (ej. reposo → caminata), la latencia es solo la de EMA + consecutivas
(el warmup ya pasó): **~10 s**.

> **Implicación para la app**: no mostrar "sin actividad" ni alarmas por ausencia de
> TLV 0x08 durante los primeros 20 s después de conectar. El estado inicial correcto
> es `RESTING (0)`.

**Logs de diagnóstico** (visibles en monitor serial mientras los TEGs de diagnóstico
están activos en el firmware):
```
I HAR: HAR ok=1 raw=[R:0.05 W:0.82 Ru:0.11 F:0.02]
I HAR: HAR ema=[R:0.15 W:0.75 Ru:0.09 F:0.01] cand=1 consec=2 → state=0
```
`state=0` aún porque `consec < 3`. Al llegar a `consec=3`, `state` cambia a 1
y se dispara el callback y el TLV 0x08.

---

### 2.5 Callback y publicación BLE

El callback `on_har_result()` en `supaclock_app.c` se invoca desde `har_task`
(core 1) cada vez que sale una inferencia procesada:

```c
static void on_har_result(const har_result_t *result, void *user) {
    // 1. Actualiza app_state (lectura por UI local del reloj)
    sd->har_state      = (uint8_t)result->state;
    sd->har_updated_ms = now_ms();

    // 2. Empuja TLV 0x08 al buffer agregado BLE (NO flush inmediato)
    uint8_t state_val = (uint8_t)result->state;
    ble_tx_push(BLE_TLV_TYPE_HAR_STATE, &state_val, 1, 0xFF);
    //                                                    ^^^^^
    //                               0xFF = no forzar flush ahora
}
```

El TLV llega a la app cuando `ble_tx_task` ejecuta el siguiente `ble_tx_flush()`,
cuya cadencia depende del modo (ver §5).

---

## 3. Protocolo BLE

### 3.1 Servicio y características

| UUID corto | UUID completo | Dirección | Tamaño | Descripción |
|---|---|---|---|---|
| `0xFF00` | `0000FF00-0000-1000-8000-00805F9B34FB` | — | — | Servicio principal SupaClock |
| `0xFF01` | `0000FF01-0000-1000-8000-00805F9B34FB` | Notify | **12 B** | IMU 6-DOF raw |
| `0xFF02` | `0000FF02-0000-1000-8000-00805F9B34FB` | Notify | variable | Telemetría agregada TLV |
| `0xFF03` | `0000FF03-0000-1000-8000-00805F9B34FB` | Notify | **20 B** | Streaming ECG |
| `0xFF04` | `0000FF04-0000-1000-8000-00805F9B34FB` | Write | **1 B** | Comandos desde app |

El nombre BLE del dispositivo contiene `SupaClock` (usado por `BleService.startScan()`).

---

### 3.2 Característica 0xFF01 — IMU raw

Notificación directa (no pasa por buffer agregado) desde `imu_task`.

**Formato** (12 bytes, little-endian):
```
Offset  Tipo    Campo
  0     int16   ax   (acelerómetro X, ±32768 LSB = ±2 g)
  2     int16   ay
  4     int16   az
  6     int16   gx   (giroscopio X, ±32768 LSB = ±250 dps)
  8     int16   gy
 10     int16   gz
```

**Cadencia**: depende del modo activo (SPORT≈50 Hz, NORMAL≈25 Hz, SAVER≈12.5 Hz),
solo cuando `app_state_imu_tx_enabled() == true` (controlado por el menú del reloj
y habilitado por defecto).

**Conversión a unidades físicas**:
```dart
double toG(int raw)   => raw / 16384.0;    // para ±2 g (16384 LSB/g)
double toDps(int raw) => raw / 131.0;      // para ±250 dps (131 LSB/dps)
```

---

### 3.3 Característica 0xFF02 — Telemetría agregada TLV

Paquete con header fijo de 6 bytes seguido de N records TLV. El firmware acumula
varios TLVs en un buffer y hace un flush periódico, lo que permite enviar múltiples
tipos de datos en una sola notificación BLE.

**Parsing Flutter** (`_onAggData`):
```dart
if (data.length < 6) return;          // validar mínimo
final powerMode  = data[4];           // byte 4
final payloadLen = data[5];           // byte 5
var off = 6;                          // inicio del payload
final end = (6 + payloadLen).clamp(0, data.length);

while (off + 2 <= end) {
    final type = data[off];
    final len  = data[off + 1];
    off += 2;
    if (off + len > end) break;       // record truncado → abortar
    // procesar payload de `len` bytes en data[off..off+len)
    off += len;
}
```

---

### 3.4 Característica 0xFF03 — Streaming ECG

Notificación directa (no pasa por buffer agregado). Solo activa cuando el modo ECG
está habilitado (comando 0x01 desde la app o desde el menú del reloj).

**Formato** (20 bytes, little-endian):
```
Offset  Tipo    Campo
  0     int16   muestra ECG 0   (ADC raw, downsampled a ≈500 Hz)
  2     int16   muestra ECG 1
  ...
 18     int16   muestra ECG 9
```
10 muestras int16 por paquete. El ADC es de 12 bits (valores 0–4095 sobre GND–3.3V),
promediado cada `ECG_DOWNSAMPLE_RATIO = 40` muestras del DMA para reducir ruido.

---

### 3.5 Característica 0xFF04 — Comandos (escritura)

La app escribe 1 byte sin respuesta (`withoutResponse: true`).

| Valor | Acción |
|---|---|
| `0x00` | Detener streaming ECG |
| `0x01` | Iniciar streaming ECG |

---

## 4. Formato de los records TLV

Cada record tiene la estructura:
```
[type: 1B][len: 1B][data: len bytes]
```
Todos los campos multi-byte son **little-endian**.

---

### 4.1 Header del paquete agregado

Siempre los primeros 6 bytes de cada notificación 0xFF02:

```
Offset  Tipo     Campo          Descripción
  0     uint32   boot_ts_ms     ms desde el boot del dispositivo (base para deltas)
  4     uint8    power_mode     Modo de energía activo (0=SPORT, 1=NORMAL, 2=SAVER)
  5     uint8    payload_len    Bytes de records TLV que siguen inmediatamente
```

Los campos `delta_ms` dentro de los TLVs son relativos a `boot_ts_ms`.
En la implementación actual, la mayoría de TLVs pone `delta_ms = 0`
(se usa el timestamp del header como referencia del paquete completo).

---

### 4.2 TLV 0x01 — Frecuencia cardíaca (HR)

```
type = 0x01
len  = 4
data:
  Offset  Tipo    Campo
    0     uint16  delta_ms   (relativo a boot_ts_ms del header; actualmente 0x0000)
    2     uint8   bpm        (latidos por minuto; 0 = sin medición válida)
    3     uint8   quality    (1=buena, 0=sin calidad declarada)
```

En modo SPORT el HR se publica cada ~1 s (modo continuo MAX30102).
En modos NORMAL/SAVER se publica al finalizar una medición SPOT.

**Flutter**: `updates['hr_bpm'] = payload.getUint8(2)` (offset 2 dentro del data del TLV).

---

### 4.3 TLV 0x02 — Saturación de oxígeno (SpO2)

```
type = 0x02
len  = 4
data:
  Offset  Tipo    Campo
    0     uint16  delta_ms   (actualmente 0x0000)
    2     uint8   pct        (porcentaje SpO2; 0 = sin medición válida)
    3     uint8   quality    (1=buena, 0=sin calidad declarada)
```

**Flutter**: `updates['spo2_pct'] = payload.getUint8(2)`.

---

### 4.4 TLV 0x03 — Temperatura corporal

```
type = 0x03
len  = 4
data:
  Offset  Tipo    Campo
    0     uint16  delta_ms    (actualmente 0x0000)
    2     int16   temp_x100   (temperatura en °C × 100; ej. 3654 = 36.54 °C)
```

**Flutter**: `updates['temp_c'] = payload.getInt16(2, Endian.little) / 100.0`.

Sensor: MAX30205 (precisión ±0.1 °C). Cadencia: según `p->temp_period_ms` del modo.

---

### 4.5 TLV 0x04 — Batería

```
type = 0x04
len  = 5
data:
  Offset  Tipo    Campo
    0     uint16  delta_ms    (actualmente 0x0000)
    2     uint16  mv          (voltaje de batería en mV; ej. 3800 = 3.800 V)
    4     uint8   soc         (estado de carga en %; 0–100)
```

**Flutter**: `updates['bat_mv'] = payload.getUint16(2, Endian.little)` y
`updates['bat_soc'] = payload.getUint8(4)`.

> **Nota**: el `soc` del TLV es `uint8` truncado de un `float` filtrado por EMA
> (α=0.1 en `system_task`). Valores posibles: 0–100. No se envía el decimal.

---

### 4.6 TLV 0x05 — Pasos acumulados

```
type = 0x05
len  = 4
data:
  Offset  Tipo    Campo
    0     uint32  total_steps   (contador acumulado desde el último reset; little-endian)
```

**Flutter**: `updates['steps'] = payload.getUint32(0, Endian.little)`.

Cadencia: cada 30 s fijos, independiente del modo (publicado desde `system_task`).
El contador puede resetearse desde el menú del reloj (opción "Reiniciar Pasos"),
lo que hace que el próximo TLV 0x05 tenga `total_steps = 0`.

El conteo usa el algoritmo FFT de podómetro software (`step_algorithm.c`), no el
step counter hardware del BMI160 (deshabilitado en producción).

---

### 4.7 TLV 0x06 — Cambio de modo de energía

```
type = 0x06
len  = 1
data:
  Offset  Tipo    Campo
    0     uint8   new_mode   (0=SPORT, 1=NORMAL, 2=SAVER)
```

Este TLV **fuerza un flush inmediato** (`flush_now_mode = new_mode`), por lo que
llega a la app sin esperar el período de flush. La app debe actualizar cualquier
indicador visual de modo al recibirlo.

**Flutter**: `updates['power_mode'] = powerMode` (del header del mismo paquete,
ya que el `ble_tx_push` pasa `new_mode` como `flush_now_mode`).

---

### 4.8 TLV 0x07 — Resultado SPOT (HR + SpO2 on-demand)

Emitido al finalizar (o abortar) una medición SPOT iniciada desde la pantalla
`HRSPOT` del reloj. También fuerza flush inmediato.

```
type = 0x07
len  = 6
data:
  Offset  Tipo    Campo
    0     uint8   bpm        (frecuencia cardíaca medida)
    1     uint8   spo2       (% SpO2 medido)
    2     uint16  dur_ms     (duración de la medición en ms; little-endian)
    4     uint8   quality    (0=POOR, 1=FAIR, 2=GOOD)
    5     uint8   aborted    (0=completado, 1=abortado o fallido)
```

**Flutter** (`_onAggData`):
```dart
case TlvTypes.spotResult:
    if (len == 6) {
        _spotController.add(SpotResult(
            bpm:         payload.getUint8(0),
            spo2:        payload.getUint8(1),
            durationMs:  payload.getUint16(2, Endian.little),
            quality:     payload.getUint8(4),
            aborted:     payload.getUint8(5) != 0,
            completedAt: DateTime.now(),
        ));
        if (!aborted) {
            updates['hr_bpm']   = bpm;
            updates['spo2_pct'] = spo2;
        }
    }
```

El `spotStream` de `BleService` emite un `SpotResult` por cada medición terminada,
independientemente de si fue exitosa o abortada.

---

### 4.9 TLV 0x08 — Estado HAR (actividad)

**El TLV de actividad del modelo HAR.** El más relevante para el equipo de la app.

```
type = 0x08
len  = 1
data:
  Offset  Tipo    Campo
    0     uint8   state   (ver tabla de estados)
```

**Tabla de estados**:

| Valor uint8 | Constante firmware (`har_state_t`) | Significado | Pantalla reloj |
|---|---|---|---|
| `0` | `HAR_STATE_RESTING` | Reposo / inactivo | "Reposo" |
| `1` | `HAR_STATE_WALKING` | Caminando | "Caminar" |
| `2` | `HAR_STATE_RUNNING` | Corriendo | "Correr" |
| `3` | `HAR_STATE_STAIRS` | Subir/bajar escaleras | "Escaleras" |

**Frecuencia de emisión**:
- El modelo infiere cada 2 s. Solo emite TLV cuando el estado **consolidado**
  cambia (si el estado se mantiene estable, se sigue enviando en cada flush).
- La app recibirá el TLV en el siguiente flush periódico de `ble_tx_task`
  (no hay flush inmediato en `on_har_result()`).
- Si no hay BLE conectado, el callback igualmente actualiza `app_state.har_state`
  para la pantalla local del reloj.

**Flutter** (`_onAggData`):
```dart
case TlvTypes.harState:
    if (len == 1) {
        updates['har_state'] = payload.getUint8(0);
    }
```

El campo `SupaClockTelemetry.harState` es un `int?` (null antes de recibir el
primer TLV 0x08). Valores válidos: 0, 1, 2, 3.

---

## 5. Cadencias de publicación por modo

Los períodos de flush del buffer agregado (0xFF02) dependen del modo:

| Modo | `ble_agg_flush_ms` | Cadencia IMU (0xFF01) | HR auto-spot | Temp/Bat |
|---|---|---|---|---|
| SPORT (0) | definido en `power_modes.c` | ~50 Hz | continuo (cada 1 s) | más frecuente |
| NORMAL (1) | mayor que SPORT | ~25 Hz | periódico (~5 min) | cada varios min |
| SAVER (2) | mayor aún | ~12.5 Hz | periódico (>10 min) | menos frecuente |

El modo actual siempre está en el byte 4 (campo `power_mode`) del header de cada
paquete 0xFF02.

> La app puede inferir el modo activo del header del paquete o del TLV 0x06 si
> el usuario lo cambia desde el reloj.

---

## 6. Enumeraciones de referencia

### Power Mode (byte 4 del header, TLV 0x06)
```dart
const int powerModeSport  = 0;
const int powerModeNormal = 1;
const int powerModeSaver  = 2;
```

### HAR State (TLV 0x08, byte 0)
```dart
const int harStateResting = 0;
const int harStateWalking = 1;
const int harStateRunning = 2;
const int harStateStairs  = 3;
```

### TLV Types (byte `type` de cada record)
```dart
class TlvTypes {
  static const int hr         = 0x01;
  static const int spo2       = 0x02;
  static const int temp       = 0x03;
  static const int bat        = 0x04;
  static const int steps      = 0x05;
  static const int modeEvt    = 0x06;
  static const int spotResult = 0x07;
  static const int harState   = 0x08;
}
```
Estos valores coinciden exactamente con las macros `BLE_TLV_TYPE_*` en
`lib/ble_telemetry/ble_telemetry.h`.

### SpotResult Quality
```dart
const int spotQualityPoor = 0;
const int spotQualityFair = 1;
const int spotQualityGood = 2;
```

---

## 7. Implementación en Flutter (BleService)

### Flujo de conexión

1. `startScan()` → busca dispositivo con nombre que contenga `"SupaClock"`.
2. `connectToDevice()` → conecta y llama a `_discoverAndSubscribe()`.
3. `_discoverAndSubscribe()` → resuelve los 4 UUIDs y suscribe:
   - `_imuChar` → `_onImuData`
   - `_aggChar` → `_onAggData`
   - `_ecgChar` → `_onEcgData`
4. `_cmdChar` se guarda para escritura bajo demanda.

### Streams disponibles

| Stream | Tipo | Descripción |
|---|---|---|
| `imuStream` | `Stream<ImuSample>` | Muestras IMU brutas (0xFF01) |
| `ecgStream` | `Stream<List<int>>` | Lotes de 10 muestras ECG (0xFF03) |
| `telemetryStream` | `Stream<SupaClockTelemetry>` | Telemetría acumulada; se emite en cada flush 0xFF02 |
| `spotStream` | `Stream<SpotResult>` | Solo emite al finalizar una medición SPOT (TLV 0x07) |

### `SupaClockTelemetry` — campos relevantes

```dart
class SupaClockTelemetry {
  final int?    heartRate;    // bpm; null = sin datos aún
  final int?    hrQuality;
  final int?    spo2;         // %; null = sin datos aún
  final int?    spo2Quality;
  final double? temperature;  // °C; null = sin datos aún
  final int?    steps;        // total; null = sin datos aún
  final int?    batteryMv;    // mV
  final int?    batterySoc;   // 0–100
  final int?    powerMode;    // 0/1/2
  final int?    harState;     // 0–3; null antes del primer TLV 0x08 (~20 s tras boot)
  final DateTime timestamp;   // DateTime.now() del último merge
}
```

El método `merge()` actualiza solo los campos presentes en el `Map<String, dynamic>`
del parse del TLV, preservando los valores anteriores para los campos no actualizados.

### Envío de comandos

```dart
await bleService.startEcgStream();  // escribe 0x01 en 0xFF04
await bleService.stopEcgStream();   // escribe 0x00 en 0xFF04
await bleService.sendCommand(0xXX); // comando arbitrario (para futuros comandos)
```

---

## 8. Contratos de no-rotura

Los siguientes aspectos son **estables** entre firmware y app. Cualquier cambio
en uno de los lados requiere actualización coordinada en el otro:

### ✅ Estable — NO cambiar sin coordinar

| Elemento | Valor fijo |
|---|---|
| UUID del servicio | `0xFF00` |
| UUID característica IMU | `0xFF01` |
| UUID característica AGG | `0xFF02` |
| UUID característica ECG | `0xFF03` |
| UUID característica CMD | `0xFF04` |
| Tamaño fijo IMU packet | **12 bytes** exactos |
| Tamaño fijo ECG packet | **20 bytes** exactos (10 × int16) |
| Endianness de todos los campos | **little-endian** |
| Offset de `power_mode` en header | **byte 4** |
| Offset de `payload_len` en header | **byte 5** |
| Inicio del primer TLV en el paquete AGG | **byte 6** |
| Valores `type` de todos los TLVs (0x01–0x08) | fijos (ver §4) |
| `len` de cada tipo TLV | fijos por tipo (ver §4) |
| Valores HAR state (0–3) | fijos (ver §6) |
| Valores power mode (0–2) | fijos (ver §6) |
| Byte de comando CMD start/stop ECG | `0x01` / `0x00` |

### ⚠️ Puede cambiar — requiere coordinación

| Elemento | Situación actual | Impacto si cambia |
|---|---|---|
| Cadencia de flush 0xFF02 | variable por modo | La app no debe asumir período fijo; usar `timestamp` |
| Cadencia 0xFF01 | variable por modo | Igual |
| Latencia primera inferencia HAR | ~16–20 s tras boot | La app debe tolerar `harState = null` sin error |
| Número de clases HAR | 4 actualmente | Si se añade clase 5, la app debe manejar `harState = 4` sin crash |
| Precisión de pasos | calibrado empiricamente | No es un valor de verdad absoluta |
| Arquitectura del modelo (`.tflite`) | ResNet-1D + LSTM | El protocolo BLE no cambia; solo afecta precisión |

### ❌ No implementado / fuera de scope

- Historial de datos (no hay almacenamiento en el reloj).
- Timestamps absolutos (solo `boot_ts_ms` relativo al boot del dispositivo).
- Comandos de configuración desde la app hacia el reloj (más allá de ECG on/off).
- Sincronización de hora desde la app al reloj.

---

*Generado el 2026-06-18. Mantener actualizado ante cambios en
`lib/ble_telemetry/ble_telemetry.h`, `lib/app_state/app_state.h`,
`lib/supaclock_app/supaclock_app.c` o `app/lib/services/ble_service.dart`.*

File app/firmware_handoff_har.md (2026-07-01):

# Handoff App → Firmware — Debug del modelo HAR y captura de datos

> Documento de coordinación **app Flutter → firmware ESP32-S3**.
> Contraparte de `ble_har_protocol.md` (que va firmware → app).
> Resume qué cambió en la app esta semana, qué **NO** requiere tocar el firmware,
> qué discrepancias hay que cerrar, y un cambio **opcional** ya especificado por si
> el equipo de firmware decide implementarlo.
>
> Objetivo: dejar lista la app para **grabar sesiones largas (1 h+) y debuggear la
> salida del modelo HAR** de cara a la presentación. Todos los formatos respetan
> los contratos de `ble_har_protocol.md §8`.

---

## ⚠️ ACTUALIZACIÓN (este avance) — el firmware YA fue integrado en el repo

El lado app pidió integrar el HAR directamente, así que **se escribió la integración
de firmware en este commit** (sin compilar/flashear — pendiente de validación del
dueño del firmware). Cambios aplicados:

- **`har_cnn1d` cableado en `supaclock_app.c`**: `har_cnn1d_init(on_har_result, NULL)`
  en una nueva "Fase 4", con `on_har_result()` que aplica **EMA (α=0.5) + consolidación
  3-consecutivas** (igual que `ble_har_protocol.md §2.4`) y publica a `app_state.har_state`
  + `ble_tx_push(BLE_TLV_TYPE_HAR_STATE, …)`.
- **`app_state.h`**: nuevos campos `har_state` + `har_updated_ms`.
- **`ble_telemetry.h`**: nuevo macro `BLE_TLV_TYPE_HAR_STATE 0x08`.
- **4ta clase redefinida**: `HAR_STATE_FALL` → **`HAR_STATE_STAIRS`** (subir/bajar
  escaleras) en `har_cnn1d.h/.c`; `fall_event` quedó obsoleto (siempre `false`).
  Propagado a protocolo, app y `tools/train_har_cnn.py` + `tools/har_replay.py`.

**Decisiones aplicadas tras revisión (este avance):**

- ✅ **Todo a 50 Hz, un solo lector.** El HAR ya NO lee el BMI160 a 100 Hz: ahora
  `imu_task` lo alimenta vía `har_cnn1d_push_sample()` con el mismo stream de 50 Hz
  que drena del FIFO. La `har_task` quedó como consumidor de inferencia (core 1,
  disparada por `xTaskNotifyGive` cada HOP). **Esto elimina la contención I2C y el
  riesgo de FIFO overflow** que tenía el diseño anterior. El modelo es 50 Hz nativo,
  así que no cambia su comportamiento. → `ble_har_protocol.md §2.2` quedó obsoleto
  en la parte de "100 Hz + promedio de 2"; conviene actualizarlo.
- ✅ **Escaleras deshabilitada por ahora.** No hay dataset de escaleras, así que el
  consumidor hace argmax solo sobre 3 clases (`HAR_ACTIVE_CLASSES=3`); el modelo
  sigue emitiendo 4 probs pero la clase 3 no se reporta. La app oculta el chip.
- ✅ **Umbrales del pedómetro calibrados con datos reales** de walking
  (`tools/calibrate_steps.py` sobre `data_ml/supaclock_imu_walking_*.csv`):
  `AMP_MIN 600→900`, `WALK_BAND_LO 0.70→0.60`. Ver §6.

**Acciones que SÍ quedan para el dueño del firmware/ML:**

1. 🔴 **Compilar + flashear y validar** la integración (es C sin probar).
2. 🔴 **Reentrenar con escaleras** cuando haya datos → subir `HAR_ACTIVE_CLASSES` a 4
   y re-habilitar el chip en la app. Pipeline: `tools/train_har_cnn.py` (ya en `stairs`)
   → `.tflite` → `har_model_data.cc`.
3. 🟡 **Validar AMP_MIN con una sesión de REPOSO** (la calibración solo tenía walking;
   confirmar que 900 rechaza el ruido en reposo sin perder pasos suaves).
4. ✅ Commitear el `.tflite` INT8 exacto (ver §3).

---

## 0. TL;DR (estado tras la integración)

| # | Tema | Estado |
|---|---|---|
| 1 | **TLV 0x08** emitido por firmware + consumido por app | ✅ **Hecho** (validar al flashear) |
| 2 | `quality` como **flag 0/1** | ✅ App alineada — solo **confirmar** semántica |
| 3 | **IMU a 50 Hz en TODOS los modos** | ⚠️ **Confirmar + actualizar** `ble_har_protocol.md §3.2/§5` |
| 4 | Exportar el **`.tflite` exacto** + **reentrenar con escaleras** | 🔴 **Pendiente** (dueño firmware/ML) |
| 5 | **TLV 0x09** opcional con probs crudas (spec abajo) | 🟡 **Opcional** |

---

## 1. Qué cambió en la app (solo informativo — no requiere firmware)

### 1.1 Consumo del TLV 0x08 (estado HAR)
`lib/services/ble_service.dart` ahora parsea el TLV `0x08` exactamente como lo
define `ble_har_protocol.md §4.9`:

```dart
case TlvTypes.harState:   // 0x08
  if (len == 1) updates['har_state'] = payload.getUint8(0);
```

- Nuevo campo `SupaClockTelemetry.harState` (`int?`, null antes del primer TLV).
- Enum `HarState` **tolerante a valores desconocidos**: si algún día emiten una
  5ª clase (`har_state = 4`), la app la muestra como "Desconocido" en vez de
  crashear (cumple el contrato `§8 → "Número de clases HAR puede cambiar"`).
- Visible en vivo en Dev Mode (chip "HAR") y grabado a CSV (ver §4).

> **No cambia nada del protocolo.** Solo confirmen que el TLV 0x08 efectivamente
> se emite en cada flush cuando hay estado consolidado.

### 1.2 Alineación del byte `quality` (HR/SpO2) — era un bug en la app
`ble_har_protocol.md §4.2/§4.3` define `quality` como **flag**:
`1 = buena, 0 = sin calidad declarada`. La app lo trataba (mal) como escala 0–100
y filtraba en `< 60`, por lo que **toda** medición con `quality=1` salía como
"señal débil" y se descartaba de las estadísticas. **Corregido en la app**: ahora
una muestra es válida con `quality >= 1`.

> **Acción firmware: solo confirmar** que el byte de `quality` en los TLV 0x01/0x02
> es 0/1 y no otra escala. Si en el futuro lo cambian a 0–100, la app sigue
> funcionando (cualquier valor ≥ 1 = válido), pero avísennos para afinar el umbral.

---

## 2. Discrepancia a cerrar: cadencia del IMU (0xFF01)

La app ahora **graba sesiones asumiendo IMU fijo a 50 Hz** (el ventaneo del modelo
en `tools/har_replay.py` usa 200 muestras = 4.0 s a 50 Hz, hop 100).

El equipo confirmó que **el firmware mantiene el IMU a 50 Hz en todos los modos de
energía**. Pero `ble_har_protocol.md` dice lo contrario en dos lugares:

- **§3.2**: *"Cadencia: depende del modo activo (SPORT≈50 Hz, NORMAL≈25 Hz, SAVER≈12.5 Hz)"*
- **§5** (tabla): *"Cadencia IMU (0xFF01): ~50 / ~25 / ~12.5 Hz"*
- **§2.1**: `imu_poll_ms` = 20/40/80 ms según modo

> **Acción firmware:** confirmar que `0xFF01` sale a **50 Hz fijo** (¿desacoplado de
> `imu_poll_ms`? ¿el `har_task` a 100 Hz alimenta también el TX?) y **actualizar
> `ble_har_protocol.md §2.1/§3.2/§5`** para que la app no tenga que asumir nada.
> Si NO es 50 Hz fijo, la app necesita grabar el período real por muestra (ya lo
> hace: cada fila lleva `timestamp_ms`), pero el replay del modelo asume 50 Hz.

---

## 3. Artefacto requerido: el `.tflite` flasheado

Para que el replay en el PC reproduzca **exactamente** lo que infiere el reloj, el
script necesita el **mismo modelo** que está flasheado.

- Flasheado: `tools/har_model_data.cc` → INT8, ~624 KB (per `ble_har_protocol.md §2.3`).
- En el repo: `tools/har_model.tflite` → **float32, ~59 KB (modelo viejo, NO coincide)**.

> **Acción firmware:** commitear el `.tflite` INT8 exacto desde el que se generó
> `har_model_data.cc` (idealmente nombrándolo claro, ej. `tools/har_model_int8.tflite`,
> o documentar el comando `xxd -i` / conversor usado). El script
> `tools/har_replay.py --model <ese.tflite>` auto-detecta float32/int8.

---

## 4. Qué captura la app (para tu referencia)

Dev Mode → tab IMU → "Grabar IMU CSV" produce un **`.csv.gz`** local (~1 MB/hora),
exportable por share sheet o `adb pull`. Formato de columnas:

```
timestamp_ms,ax,ay,az,gx,gy,gz,label,temp_c,steps,bat_mv,bat_soc,hr_bpm,spo2_pct,har_state
```

- `ax..gz`: IMU crudo int16 tal cual `0xFF01` (sin convertir; el replay normaliza /32768).
- `label`: etiqueta **manual** elegida en la app (`resting/walking/running/fall`) = ground-truth.
- `har_state`: **salida consolidada del reloj** (TLV 0x08; `-1` = warmup/sin inferencia).
- resto: último valor visto de la telemetría agregada (0xFF02).

Tener `label` (manual) **y** `har_state` (modelo) en cada fila permite matriz de
confusión reloj-vs-realidad sin reconstruir nada.

`tools/har_replay.py sesion.csv.gz --plot out.png` → reconstruye probs (re-corriendo
el `.tflite`), replica EMA α=0.5 + 3-consecutivas (`§2.4`), y saca tiempo por
actividad, matrices de confusión y gráficos. Runtime: `pip install ai-edge-litert`.

---

## 5. (OPCIONAL) Propuesta de TLV 0x09 — probs de debug

**Solo si el equipo de firmware quiere validación directa** sin que el PC reconstruya
las probs. Hoy las probs `probs[4]` no salen del firmware (`§2.5`); el PC las
recalcula corriendo el mismo modelo. Un TLV de debug las pondría on-wire para
comparar 1:1 contra el reconstruido y descartar diferencias de cuantización.

Diseño respetando el formato TLV existente (`[type:1B][len:1B][data]`, little-endian):

```
type = 0x09   (BLE_TLV_TYPE_HAR_DEBUG; 0x09 está libre, 0x01–0x08 ocupados)
len  = 8
data:
  Offset  Tipo    Campo            Descripción
    0     uint16  p_rest_x10000    prob RESTING × 10000  (0..10000)
    2     uint16  p_walk_x10000    prob WALKING × 10000
    4     uint16  p_run_x10000     prob RUNNING × 10000
    6     uint16  p_fall_x10000    prob FALL    × 10000
```

**Emisión sugerida:** una vez por inferencia (cada 2 s), **gateada por un flag de
debug** para no gastar ancho de banda en producción — análogo al `pedDbg` (0x10)
que ya usan para calibrar el podómetro. Se puede empujar con
`ble_tx_push(BLE_TLV_TYPE_HAR_DEBUG, buf, 8, 0xFF)` junto al 0x08.

**Activación (opcional, si quieren togglearlo desde la app)** — siguiendo el patrón
del char de comandos `0xFF04` (hoy `0x00`/`0x01` = ECG off/on):

```
0x02 = iniciar streaming de probs HAR (TLV 0x09)
0x03 = detener streaming de probs HAR
```

Si implementan esto, avísenme y agrego el parseo del 0x09 + el botón en Dev Mode
(es ~10 líneas en `ble_service.dart`, misma estructura que el `case` del 0x08).

**Si EMA on-device también interesa** (para validar el filtro, no solo el modelo),
se puede extender a `len = 16` con otros 4×uint16 de `s_probs_ema[]`. Lo dejo fuera
por defecto para mantenerlo mínimo.

---
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

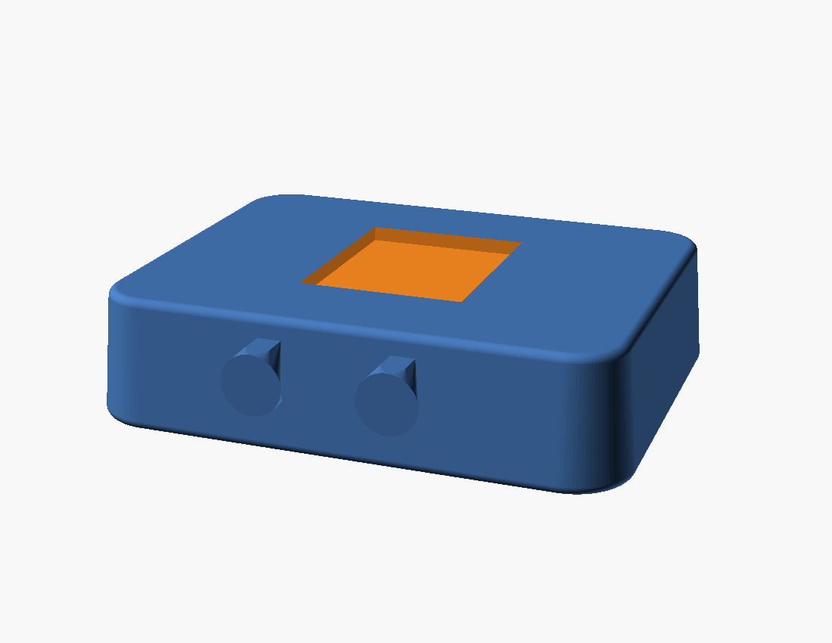
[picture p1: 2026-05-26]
mechanical/render_v2_quarter.png

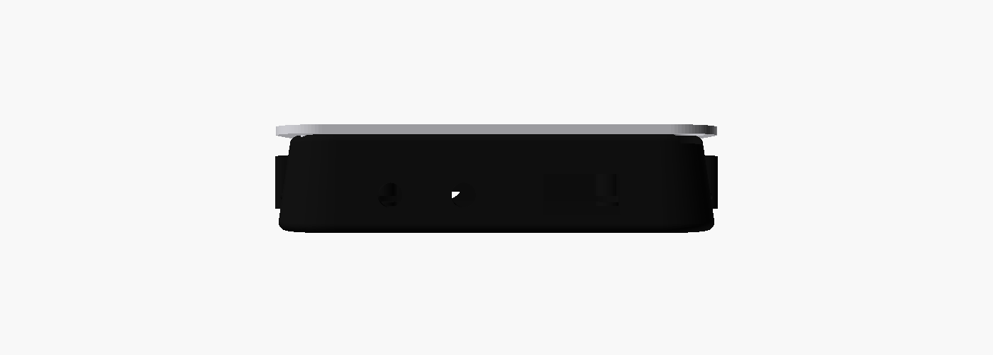
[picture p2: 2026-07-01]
mechanical/renders_v3/v3_side.png

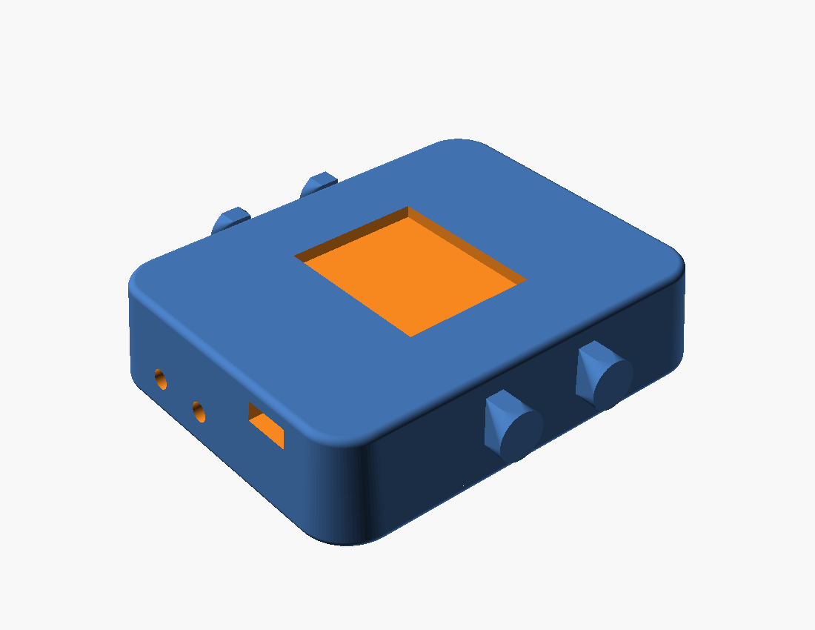
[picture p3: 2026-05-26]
mechanical/render_v2_hero.png

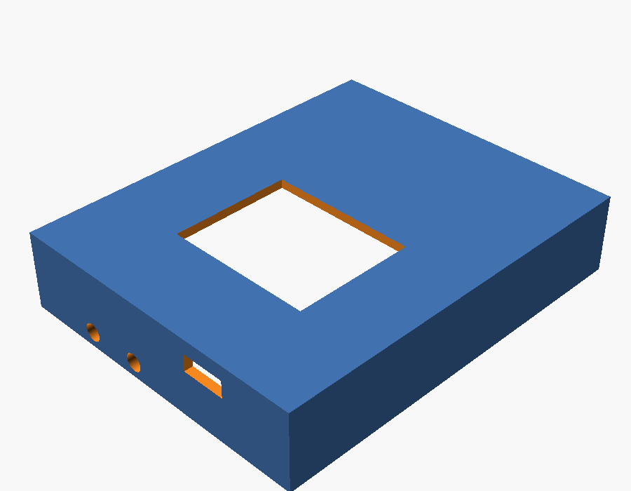
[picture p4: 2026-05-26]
mechanical/render_top_iso.png

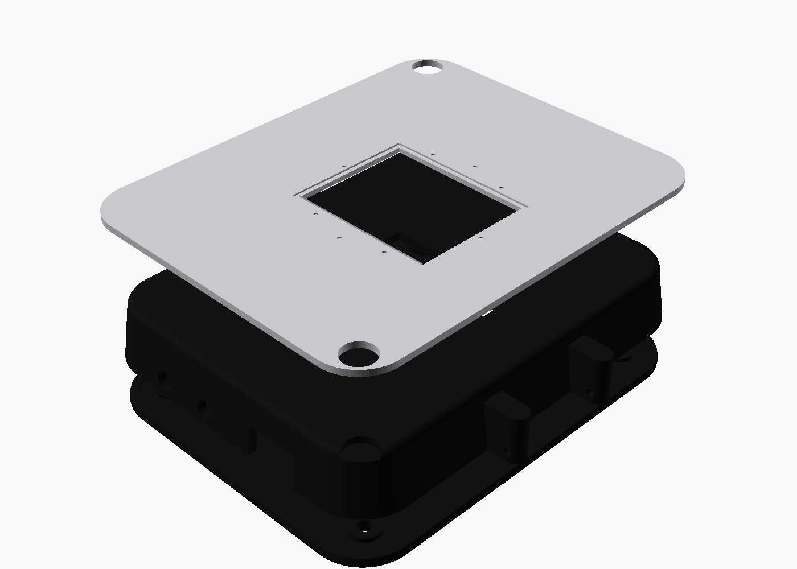
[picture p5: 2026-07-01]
mechanical/renders_v3/v3_classic_exploded_3layers.png

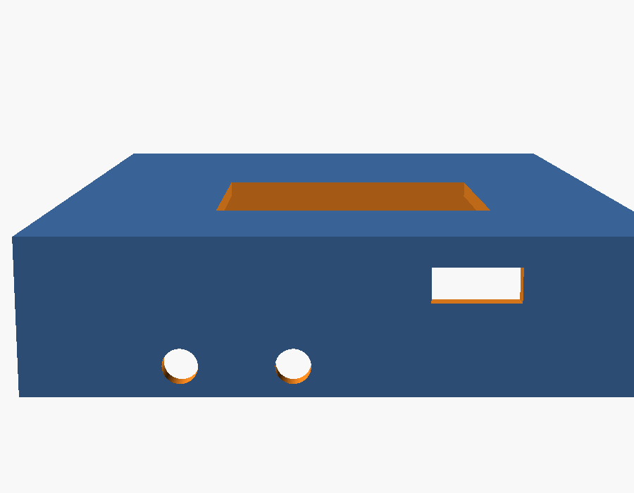
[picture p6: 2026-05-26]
mechanical/render_top_right_wall.png

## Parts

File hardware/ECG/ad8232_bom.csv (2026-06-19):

Reference | Value | Footprint
C1 | 1.5nF | AD8232_Heart_Rate_Monitor:0603-CAP
C2 | 1nF | AD8232_Heart_Rate_Monitor:0603-CAP
C3 | 10nF | AD8232_Heart_Rate_Monitor:0603-CAP
C4 | 0.33uF | AD8232_Heart_Rate_Monitor:0805
C5 | 0.1uF | AD8232_Heart_Rate_Monitor:0603-CAP
C6 | 0.33uF | AD8232_Heart_Rate_Monitor:0805
C7 | 0.1uf | AD8232_Heart_Rate_Monitor:0603-CAP
D1 | RED | AD8232_Heart_Rate_Monitor:LED-0603
FID1 | FIDUCIAL1X2 | AD8232_Heart_Rate_Monitor:FIDUCIAL-1X2
FID2 | FIDUCIAL1X2 | AD8232_Heart_Rate_Monitor:FIDUCIAL-1X2
FRAME1 | FRAME-LETTER | AD8232_Heart_Rate_Monitor:CREATIVE_COMMONS
JP1 | M03PTH | AD8232_Heart_Rate_Monitor:1X03
JP2 | AUDIO-JACKSMD2 | AD8232_Heart_Rate_Monitor:AUDIO-JACK-3.5MM-SMD
JP3 | M06SIP | AD8232_Heart_Rate_Monitor:1X06
LOGO1 | OSHW-LOGOS | AD8232_Heart_Rate_Monitor:OSHW-LOGO-S
LOGO2 | SFE_LOGO_NAME_FLAME.1_INCH | AD8232_Heart_Rate_Monitor:SFE_LOGO_NAME_FLAME_.1
R1 | 10M | AD8232_Heart_Rate_Monitor:0603-RES
R2 | 10M | AD8232_Heart_Rate_Monitor:0603-RES
R3 | 180k | AD8232_Heart_Rate_Monitor:0603-RES
R4 | 180k | AD8232_Heart_Rate_Monitor:0603-RES
R5 | 360k | AD8232_Heart_Rate_Monitor:0603-RES
R6 | 1M | AD8232_Heart_Rate_Monitor:0603-RES
R7 | 1M | AD8232_Heart_Rate_Monitor:0603-RES
R8 | 100k | AD8232_Heart_Rate_Monitor:0603-RES
R9 | 1M | AD8232_Heart_Rate_Monitor:0603-RES
R10 | 10M | AD8232_Heart_Rate_Monitor:0603-RES
R11 | 10M | AD8232_Heart_Rate_Monitor:0603-RES
R12 | 1.4M | AD8232_Heart_Rate_Monitor:0603-RES
R13 | 10M | AD8232_Heart_Rate_Monitor:0603-RES
R14 | 10M | AD8232_Heart_Rate_Monitor:0603-RES
R15 | 10K | AD8232_Heart_Rate_Monitor:0603-RES
R16 | 1k | AD8232_Heart_Rate_Monitor:0603-RES
R17 | 0 | AD8232_Heart_Rate_Monitor:0603
R18 | DNP | AD8232_Heart_Rate_Monitor:0603
R19 | 0 | AD8232_Heart_Rate_Monitor:0603
R20 | DNP | AD8232_Heart_Rate_Monitor:0603
SJ4 | LED DISABLE | AD8232_Heart_Rate_Monitor:SJ_2S-TRACE
STANDOFF1 | STAND-OFF | AD8232_Heart_Rate_Monitor:STAND-OFF
STANDOFF2 | STAND-OFF | AD8232_Heart_Rate_Monitor:STAND-OFF
STANDOFF3 | STAND-OFF | AD8232_Heart_Rate_Monitor:STAND-OFF
STANDOFF4 | STAND-OFF | AD8232_Heart_Rate_Monitor:STAND-OFF
U1 | AD8232 | AD8232_Heart_Rate_Monitor:LFCSP_20

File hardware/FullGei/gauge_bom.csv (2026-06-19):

Reference | Value | Footprint
C1 | 1.0uF | SparkFun_Lipo_Fuel_Gauge:0402-TIGHT
C2 | 10nF | SparkFun_Lipo_Fuel_Gauge:0402-TIGHT
FRAME1 | FRAME-LETTER | SparkFun_Lipo_Fuel_Gauge:CREATIVE_COMMONS
I2C0 | JUMPER-SMT_3_2-NC_TRACE_SILK | SparkFun_Lipo_Fuel_Gauge:SMT-JUMPER_3_2-NC_TRACE_SILK
JP1 | input | SparkFun_Lipo_Fuel_Gauge:JST-2-SMD
JP2 | CONN_031X03_NO_SILK | SparkFun_Lipo_Fuel_Gauge:1X03_NO_SILK
JP3 | SFE_LOGO_FLAME.1_INCH | SparkFun_Lipo_Fuel_Gauge:SFE_LOGO_FLAME_.1
JP4 | CONN_031X03_NO_SILK | SparkFun_Lipo_Fuel_Gauge:1X03_NO_SILK
JP5 | CONN_021X02_NO_SILK | SparkFun_Lipo_Fuel_Gauge:1X02_NO_SILK
JP6 | FIDUCIALUFIDUCIAL | SparkFun_Lipo_Fuel_Gauge:FIDUCIAL-MICRO
JP7 | FIDUCIALUFIDUCIAL | SparkFun_Lipo_Fuel_Gauge:FIDUCIAL-MICRO
JP8 | FIDUCIALUFIDUCIAL | SparkFun_Lipo_Fuel_Gauge:FIDUCIAL-MICRO
JP9 | FIDUCIALUFIDUCIAL | SparkFun_Lipo_Fuel_Gauge:FIDUCIAL-MICRO
LOGO1 | SFE_LOGO_NAME_FLAMEBLANK | SparkFun_Lipo_Fuel_Gauge:BLANK
R1 | 1k | SparkFun_Lipo_Fuel_Gauge:0402-TIGHT
R2 | 100 | SparkFun_Lipo_Fuel_Gauge:0402-TIGHT
R3 | 2.2k | SparkFun_Lipo_Fuel_Gauge:0402-TIGHT
R4 | 2.2k | SparkFun_Lipo_Fuel_Gauge:0402-TIGHT
R5 | 2.2k | SparkFun_Lipo_Fuel_Gauge:0402-TIGHT
R6 | 2.2k | SparkFun_Lipo_Fuel_Gauge:0402-TIGHT
U$1 | OSHW-LOGOS | SparkFun_Lipo_Fuel_Gauge:OSHW-LOGO-S
U2 | MAX1704X | SparkFun_Lipo_Fuel_Gauge:TDFN-8

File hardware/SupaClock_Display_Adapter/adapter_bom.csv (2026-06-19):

Reference | Value | Footprint
C1 | 10uF | Capacitor_THT:CP_Radial_D5.0mm_P2.50mm
C2 | 100nF | Capacitor_THT:C_Disc_D3.0mm_W1.6mm_P2.50mm
J1 | Conn_01x08 | Connector_PinHeader_2.54mm:PinHeader_1x08_P2.54mm_Vertical
J2 | Conn_01x24 | Connector_FFC-FPC:Hirose_FH12-24S-0.5SH_1x24-1MP_P0.50mm_Horizontal
Q1 | 2N7000 | Package_TO_SOT_THT:TO-92_Inline
R1 | 10k | Resistor_THT:R_Axial_DIN0207_L6.3mm_D2.5mm_P10.16mm_Horizontal
R2 | 22 | Resistor_THT:R_Axial_DIN0207_L6.3mm_D2.5mm_P10.16mm_Horizontal
R3 | 10k | Resistor_THT:R_Axial_DIN0207_L6.3mm_D2.5mm_P10.16mm_Horizontal
R4 | 10k | Resistor_THT:R_Axial_DIN0207_L6.3mm_D2.5mm_P10.16mm_Horizontal
R5 | 10k | Resistor_THT:R_Axial_DIN0207_L6.3mm_D2.5mm_P10.16mm_Horizontal

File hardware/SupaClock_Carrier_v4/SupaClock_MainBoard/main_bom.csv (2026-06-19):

Reference | Value | Footprint
C2 | 10uF | Capacitor_THT:CP_Radial_D5.0mm_P2.50mm
C3 | 100nF | Capacitor_THT:C_Disc_D5.0mm_W2.5mm_P5.00mm
C4 | 100nF | Capacitor_THT:C_Disc_D5.0mm_W2.5mm_P5.00mm
C5 | 100nF | Capacitor_THT:C_Disc_D5.0mm_W2.5mm_P5.00mm
C6 | 100nF | Capacitor_THT:C_Disc_D5.0mm_W2.5mm_P5.00mm
J3 | MAX30102_top | SupaClock_Custom:MAX30102_Castellated_1x4
J4 | MAX30205_8pad | SupaClock_Custom:MAX30205_8pad_Flush
J5 | BMI160_7p | Connector_PinSocket_2.54mm:PinSocket_1x07_P2.54mm_Vertical
J6a1 | MAX17048_L | Connector_PinSocket_2.54mm:PinSocket_1x03_P2.54mm_Vertical
J6b1 | MAX17048_R | Connector_PinSocket_2.54mm:PinSocket_1x03_P2.54mm_Vertical
J6c1 | MAX17048_BAT | Connector_PinSocket_2.54mm:PinSocket_1x02_P2.54mm_Vertical
J7 | ST7789_1.69in | Connector_PinSocket_2.54mm:PinSocket_1x08_P2.54mm_Vertical
J11 | AD8232_SparkFun | Connector_PinSocket_2.54mm:PinSocket_1x06_P2.54mm_Vertical
J12_LA1 | ECG_LA_pad_M3 | SupaClock_Custom:M3_Electrode_Pad
J12_RA1 | ECG_RA_pad_M3 | SupaClock_Custom:M3_Electrode_Pad
J12_RL1 | ECG_RL_pad_M3 | SupaClock_Custom:M3_Electrode_Pad
J13 | AD8232_Pads_RA_LA_RL | Connector_PinSocket_2.54mm:PinSocket_1x03_P2.54mm_Vertical
J14 | MAX30102_bot | SupaClock_Custom:MAX30102_Castellated_1x4
R1 | 4.7k | Resistor_THT:R_Axial_DIN0207_L6.3mm_D2.5mm_P7.62mm_Horizontal
R2 | 4.7k | Resistor_THT:R_Axial_DIN0207_L6.3mm_D2.5mm_P7.62mm_Horizontal
R3 | 10k | Resistor_THT:R_Axial_DIN0207_L6.3mm_D2.5mm_P7.62mm_Horizontal
R4 | 10k | Resistor_THT:R_Axial_DIN0207_L6.3mm_D2.5mm_P7.62mm_Horizontal
R5 | 10k | Resistor_THT:R_Axial_DIN0207_L6.3mm_D2.5mm_P7.62mm_Horizontal
SW1 | SELECT | SupaClock_Custom:SW_Tactile_Side_3.5x7.8mm
SW2 | NEXT | SupaClock_Custom:SW_Tactile_Side_3.5x7.8mm
U1 | XIAO-ESP32-S3 | SupaClock_Custom:XIAO-ESP32-S3-SMD

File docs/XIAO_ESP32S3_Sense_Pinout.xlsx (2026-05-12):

Name | No. | Type | Power Domain | Function
LNA_IN | 1 | I/O | — | RF input and output
VDD3P3 | 2 | PA | — | Analog Power
VDD3P3 | 3 | PA | — | Analog Power
CHIP_PU | 4 | I | VDD3P3_RTC | High level: chip enable; Low: chip off; Note that the CHIP_PU pin cannot be left floating.
GPIO0 | 5 | I/O/T | VDD3P3_RTC | RTC_GPIO0 | GPIO0 |  |  |  |  |  | BOOT
GPIO1 | 6 | I/O/T | VDD3P3_RTC | RTC_GPIO1 | GPIO1 | TOUCH1 | ADC1_CH0 |  |  |  | D0 | A0 | GPIO1 | TOUCH1
GPIO2 | 7 | I/O/T | VDD3P3_RTC | RTC_GPIO2 | GPIO2 | TOUCH2 | ADC1_CH1 |  |  |  | D1 | A1 | GPIO2 | TOUCH2
GPIO3 | 8 | I/O/T | VDD3P3_RTC | RTC_GPIO3 | GPIO3 | TOUCH3 | ADC1_CH2 |  |  |  | D2 | A2 | GPIO3 | TOUCH3
GPIO4 | 9 | I/O/T | VDD3P3_RTC | RTC_GPIO4 | GPIO4 | TOUCH4 | ADC1_CH3 |  |  |  | D3 | A3 | GPIO4 | TOUCH4
GPIO5 | 10 | I/O/T | VDD3P3_RTC | RTC_GPIO5 | GPIO5 | TOUCH5 | ADC1_CH4 |  |  |  | D4 | A4 | GPIO5 | TOUCH5 | SDA
GPIO6 | 11 | I/O/T | VDD3P3_RTC | RTC_GPIO6 | GPIO6 | TOUCH6 | ADC1_CH5 |  |  |  | D5 | A5 | GPIO6 | TOUCH6 | SCL
GPIO7 | 12 | I/O/T | VDD3P3_RTC | RTC_GPIO7 | GPIO7 | TOUCH7 | ADC1_CH6 |  |  |  | D8 | A8 | GPIO7 | TOUCH7 | SCK
GPIO8 | 13 | I/O/T | VDD3P3_RTC | RTC_GPIO8 | GPIO8 | TOUCH8 | ADC1_CH7 | SUBSPICS1 |  |  | D9 | A9 | GPIO8 | TOUCH8 | MISO
GPIO9 | 14 | I/O/T | VDD3P3_RTC | RTC_GPIO9 | GPIO9 | TOUCH9 | ADC1_CH8 | SUBSPIHD | FSPIHD |  | D10 | A10 | GPIO9 | TOUCH9 | MOSI
GPIO10 | 15 | I/O/T | VDD3P3_RTC | RTC_GPIO10 | GPIO10 | TOUCH10 | ADC1_CH9 | FSPIIO4 | SUBSPICS0 | FSPICS0 | XMCLK |  | GPIO10
GPIO11 | 16 | I/O/T | VDD3P3_RTC | RTC_GPIO11 | GPIO11 | TOUCH11 | ADC2_CH0 | FSPIIO5 | SUBSPID | FSPID | Y8 |  | GPIO11
GPIO12 | 17 | I/O/T | VDD3P3_RTC | RTC_GPIO12 | GPIO12 | TOUCH12 | ADC2_CH1 | FSPIIO6 | SUBSPICLK | FSPICLK | Y7 |  | GPIO12
GPIO13 | 18 | I/O/T | VDD3P3_RTC | RTC_GPIO13 | GPIO13 | TOUCH13 | ADC2_CH2 | FSPIIO7 | SUBSPIQ | FSPIQ | PCLK |  | GPIO13
GPIO14 | 19 | I/O/T | VDD3P3_RTC | RTC_GPIO14 | GPIO14 | TOUCH14 | ADC2_CH3 | FSPIDQS | SUBSPIWP | FSPIWP | Y6 |  | GPIO14
VDD3P3_RTC | 20 | PA | — | Analog Power
XTAL_32K_P | 21 | I/O/T | VDD3P3_RTC | RTC_GPIO15 | GPIO15 | U0RTS | ADC2_CH4 | XTAL_32K_P |  |  | Y2 |  | GPIO15
XTAL_32K_N | 22 | I/O/T | VDD3P3_RTC | RTC_GPIO16 | GPIO16 | U0CTS | ADC2_CH5 | XTAL_32K_N |  |  | Y5 |  | GPIO16
GPIO17 | 23 | I/O/T | VDD3P3_RTC | RTC_GPIO17 | GPIO17 | U1TXD | ADC2_CH6 |  |  |  | Y3 |  | GPIO17
GPIO18 | 24 | I/O/T | VDD3P3_RTC | RTC_GPIO18 | GPIO18 | U1RXD | ADC2_CH7 | CLK_OUT3 |  |  | Y4 |  | GPIO18
GPIO19 | 25 | I/O/T | VDD3P3_RTC | RTC_GPIO19 | GPIO19 | U1RTS | ADC2_CH8 | CLK_OUT2 | USB_D- |  | D-
GPIO20 | 26 | I/O/T | VDD3P3_RTC | RTC_GPIO20 | GPIO20 | U1CTS | ADC2_CH9 | CLK_OUT1 | USB_D+ |  | D+
GPIO21 | 27 | I/O/T | VDD3P3_RTC | RTC_GPIO21 | GPIO21 |  |  |  |  |  | User_LED |  | GPIO21
SPICS1 | 28 | I/O/T | VDD_SPI | SPICS1 | GPIO26
VDD_SPI | 29 | PD | — | 1.8 V or VDD3P3_RTC power output
SPIHD | 30 | I/O/T | VDD_SPI | SPIHD | GPIO27
SPIWP | 31 | I/O/T | VDD_SPI | SPIWP | GPIO28
SPICS0 | 32 | I/O/T | VDD_SPI | SPICS0 | GPIO29
SPICLK | 33 | I/O/T | VDD_SPI | SPICLK | GPIO30
SPIQ | 34 | I/O/T | VDD_SPI | SPIQ | GPIO31
SPID | 35 | I/O/T | VDD_SPI | SPID | GPIO32
SPICLK_N | 36 | I/O/T | VDD_SPI | SPICLK_N_DIFF | GPIO48 | SUBSPICLK_N_DIFF |  |  |  |  | Y9 |  | GPIO48
SPICLK_P | 37 | I/O/T | VDD_SPI | SPICLK_P_DIFF | GPIO47 | SUBSPICLK_P_DIFF |  |  |  |  | HREF |  | GPIO47
GPIO33 | 38 | I/O/T | VDD3P3_CPU / VDD_SPI | SPIIO4 | GPIO33 | FSPIHD | SUBSPIHD
GPIO34 | 39 | I/O/T | VDD3P3_CPU / VDD_SPI | SPIIO5 | GPIO34 | FSPICS0 | SUBSPICS0
GPIO35 | 40 | I/O/T | VDD3P3_CPU / VDD_SPI | SPIIO6 | GPIO35 | FSPID | SUBSPID
GPIO36 | 41 | I/O/T | VDD3P3_CPU / VDD_SPI | SPIIO7 | GPIO36 | FSPICLK | SUBSPICLK
GPIO37 | 42 | I/O/T | VDD3P3_CPU / VDD_SPI | SPIDQS | GPIO37 | FSPIQ | SUBSPIQ
GPIO38 | 43 | I/O/T | VDD3P3_CPU | GPIO38 | FSPIWP | SUBSPIWP |  |  |  |  | VSYNC |  | GPIO38
MTCK | 44 | I/O/T | VDD3P3_CPU | MTCK | GPIO39 | CLK_OUT3 | SUBSPICS1 |  |  |  | Cam_SCL |  | GPIO39 | MTCK
MTDO | 45 | I/O/T | VDD3P3_CPU | MTDO | GPIO40 | CLK_OUT2 |  |  |  |  | Cam_SDA |  | GPIO40 | MTDO
VDD3P3_CPU | 46 | PD | — | CPU IO power input
MTDI | 47 | I/O/T | VDD3P3_CPU | MTDI | GPIO41 | CLK_OUT1 |  |  |  |  | D12 | PDM_DATA | GPIO41 | MTDI
MTMS | 48 | I/O/T | VDD3P3_CPU | MTMS | GPIO42 |  |  |  |  |  | D11 | PDM_CLK | GPIO42 | MTMS
U0TXD | 49 | I/O/T | VDD3P3_CPU | U0TXD | GPIO43 | CLK_OUT1 |  |  |  |  | D6 | TX | GPIO43
U0RXD | 50 | I/O/T | VDD3P3_CPU | U0RXD | GPIO44 | CLK_OUT2 |  |  |  |  | D7 | RX | GPIO44
GPIO45 | 51 | I/O/T | VDD3P3_CPU | GPIO45
GPIO46 | 52 | I/O/T | VDD3P3_CPU | GPIO46
XTAL_N | 53 | — | — | External master crystal output
XTAL_P | 54 | — | — | External master crystal input
VDDA1 | 55 | PA | — | Analog Power
VDDA2 | 56 | PA | — | Analog Power
GND | 57 | G | — | GND
 |  |  |  |  |  |  |  |  |  | BOOT
 |  |  |  |  |  |  |  |  |  | JTAG
 |  |  |  |  |  |  |  |  |  | Camera
 |  |  |  |  |  |  |  |  |  | TOUCH
 |  |  |  |  |  |  |  |  |  | SPI
 |  |  |  |  |  |  |  |  |  | ALL PWM
 |  |  |  |  |  |  |  |  |  | USB
 |  |  |  |  |  |  |  |  |  | Analog
 |  |  |  |  |  |  |  |  |  | IIC
 |  |  |  |  |  |  |  |  |  | Digital
 |  |  |  |  |  |  |  |  |  | GPIO
 |  |  |  |  |  |  |  |  |  | MIC
 |  |  |  |  |  |  |  |  |  | UART
 |  |  |  |  | BPI-PicoW-S3 外设GPIO管脚分配
 |  |  |  |  | 外设接口 | 信号 | 管脚
 |  |  |  |  | ADC | ADC1_CH0~9 | GPIO 1~10
 |  |  |  |  |  | ADC2_CH0~9 | GPIO 11~20
 |  |  |  |  | 触摸传感器 | TOUCH1~14 | GPIO 1~14
 |  |  |  |  | JTAG | MTCK | GPIO 39
 |  |  |  |  |  | MTDO | GPIO 40
 |  |  |  |  |  | MTDI | GPIO 41
 |  |  |  |  |  | MTMS | GPIO 42
 |  |  |  |  | UART | 默认分配管脚，可重定义为任意GPIO
 |  |  |  |  |  | U0RXD_in | GPIO 44
 |  |  |  |  |  | U0CTS_in | GPIO 16
 |  |  |  |  |  | U0DSR_in | 任意GPIO
 |  |  |  |  |  | U0TXD_out | GPIO43
 |  |  |  |  |  | U0RTS_out | GPIO 15
 |  |  |  |  |  | U0DTR_out | 任意GPIO
 |  |  |  |  |  | U1RXD_in | GPIO 18
 |  |  |  |  |  | U1CTS_in | GPIO 20
 |  |  |  |  |  | U1DSR_in | 任意GPIO
 |  |  |  |  |  | U1TXD_out | GPIO 17
 |  |  |  |  |  | U1RTS_out | GPIO 19
 |  |  |  |  |  | U1DTR_out | 任意GPIO
 |  |  |  |  |  | U2 | 任意GPIO
 |  |  |  |  | I2C | 任意GPIO
 |  |  |  |  | PWM | 任意GPIO
 |  |  |  |  | I2S | 任意GPIO
 |  |  |  |  | LCD | 任意GPIO
 |  |  |  |  | CAMERA | 任意GPIO
 |  |  |  |  | RMT | 任意GPIO
 |  |  |  |  | SPI0/1 | 已用于FLASH与PSRAM
 |  |  |  |  | SPI2/3 | 任意GPIO
 |  |  |  |  | 脉冲计数器 | 任意GPIO
 |  |  |  |  | USB OTG | D- | GPIO 19（内部 PHY）
 |  |  |  |  |  | D+ | GPIO 20（内部 PHY）
 |  |  |  |  |  | VP | GPIO 42（外部 PHY）
 |  |  |  |  |  | VM | GPIO 41（外部 PHY）
 |  |  |  |  |  | RCV | GPIO21（外部 PHY）
 |  |  |  |  |  | OEN | GPIO 40（外部 PHY）
 |  |  |  |  |  | VPO | GPIO 39（外部 PHY）
 |  |  |  |  |  | VMO | GPIO38（外部 PHY）
 |  |  |  |  | USB Serial/JTAG | D- | GPIO 19（内部 PHY）
 |  |  |  |  |  | D+ | GPIO 20（内部 PHY）
 |  |  |  |  |  | VP | GPIO 42（外部 PHY）
 |  |  |  |  |  | VM | GPIO 41（外部 PHY）
 |  |  |  |  |  | OEN | GPIO 40（外部 PHY）
 |  |  |  |  |  | VPO | GPIO 39（外部 PHY）
 |  |  |  |  |  | VMO | GPIO38（外部 PHY）
 |  |  |  |  | SD/MMC | 任意GPIO
 |  |  |  |  | MCPWM | 任意GPIO
 |  |  |  |  | TWAI | 任意GPIO
 |  |  |  |  | 彩色LED | GPIO 48
 |  |  |  |  | 单色LED | GPIO 46

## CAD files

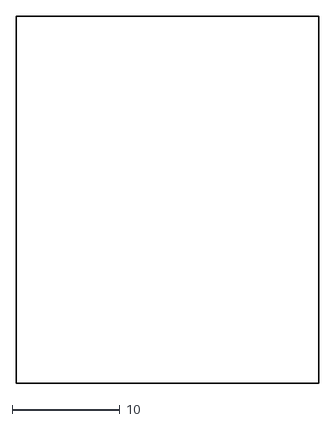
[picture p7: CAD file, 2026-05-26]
mechanical/dxf_sketches/top_cuts.dxf
28.0 x 34.0

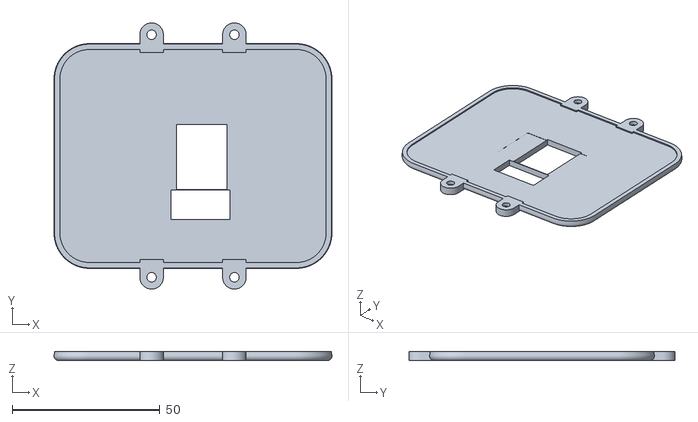
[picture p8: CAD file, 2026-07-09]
mechanical/stl_v4/supaclock_v4_bottom.stl
94.0 x 90.0 x 3.00

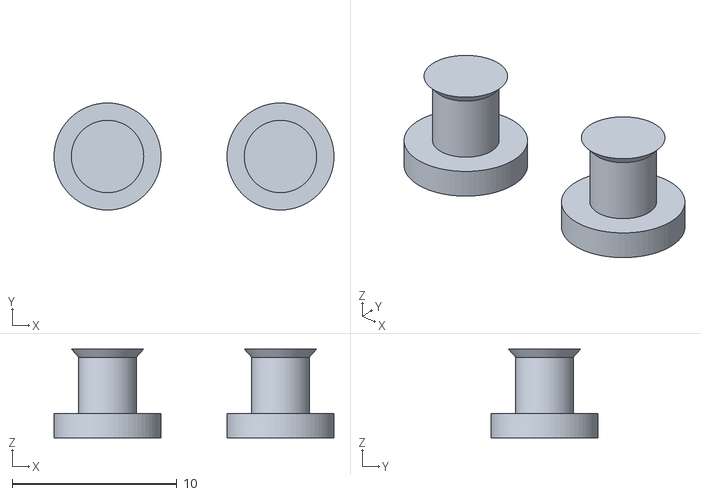
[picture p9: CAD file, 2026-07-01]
mechanical/supaclock_button_caps.stl
17.0 x 6.50 x 5.40

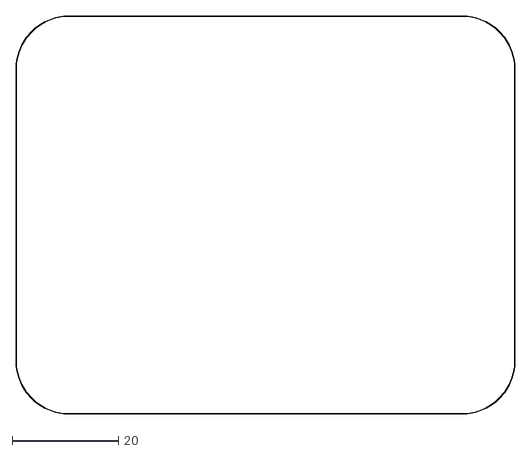
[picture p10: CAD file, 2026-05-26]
mechanical/dxf_sketches/inner_cavity.dxf
94.0 x 75.0

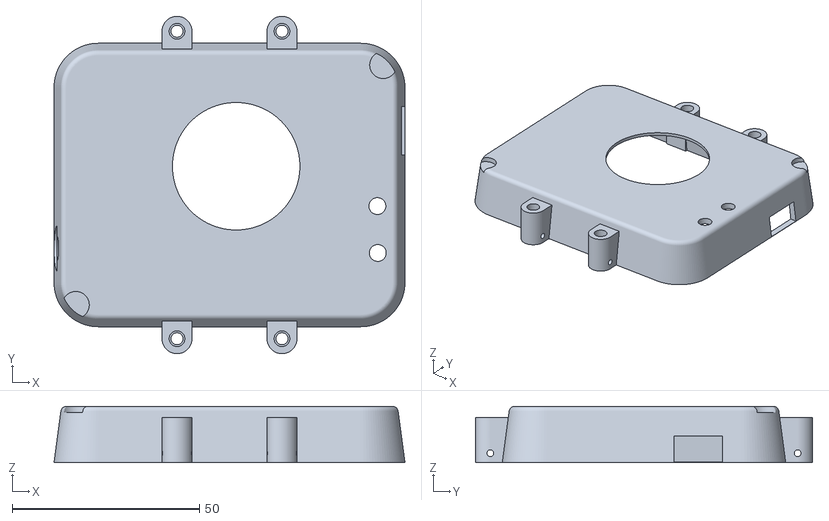
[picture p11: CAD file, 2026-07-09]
mechanical/stl_v4/supaclock_v4_top_magnetic.stl
93.6 x 90.0 x 15.0

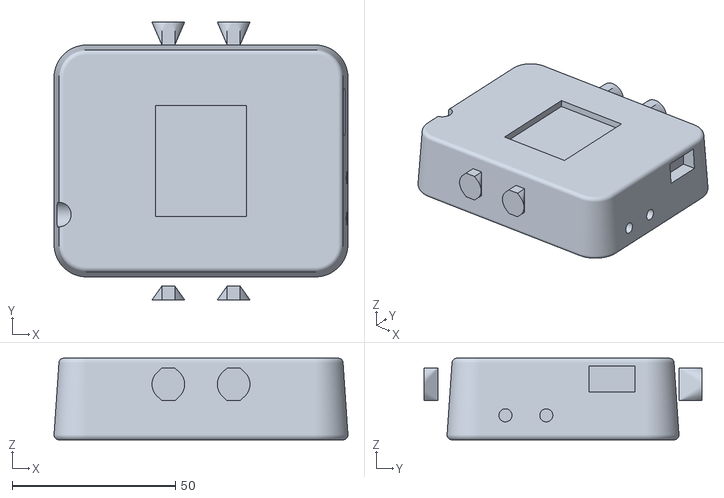
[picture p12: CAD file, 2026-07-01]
mechanical/supaclock_v2_concept.stl
90.0 x 85.0 x 25.0

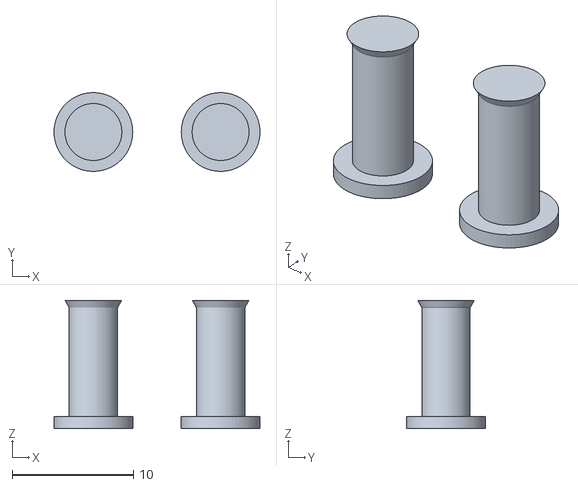
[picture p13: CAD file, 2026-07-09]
mechanical/stl_v4/supaclock_v4_button_caps.stl
17.0 x 6.50 x 10.6

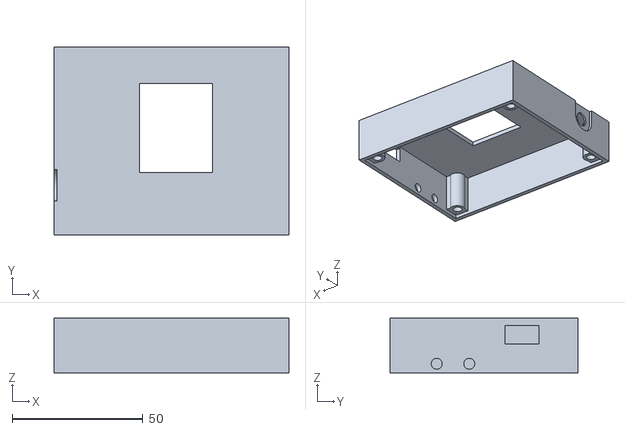
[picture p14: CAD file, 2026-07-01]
mechanical/supaclock_top_case.stl
90.0 x 72.0 x 21.0

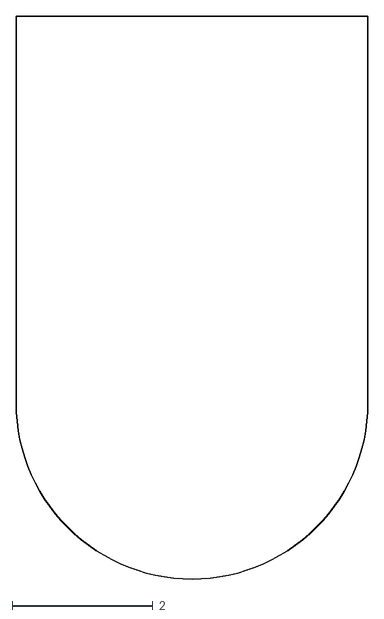
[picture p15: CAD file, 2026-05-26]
mechanical/dxf_sketches/lug.dxf
5.00 x 8.00

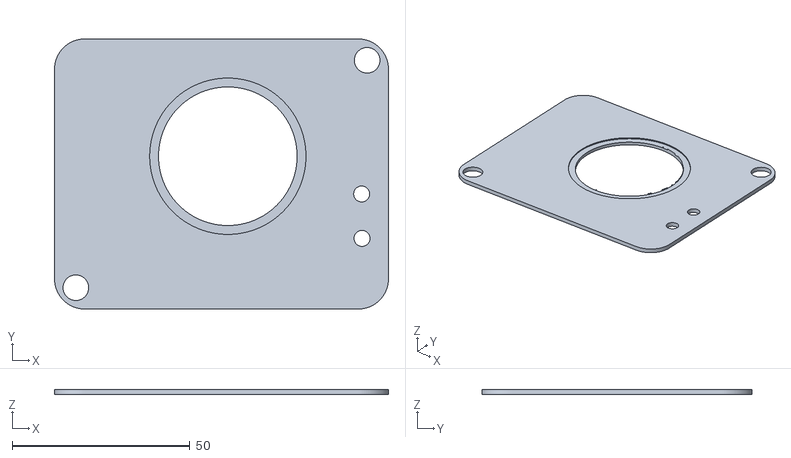
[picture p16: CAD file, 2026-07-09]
mechanical/stl_v4/supaclock_v4_face_minimal_magnetic.stl
94.0 x 76.0 x 1.50

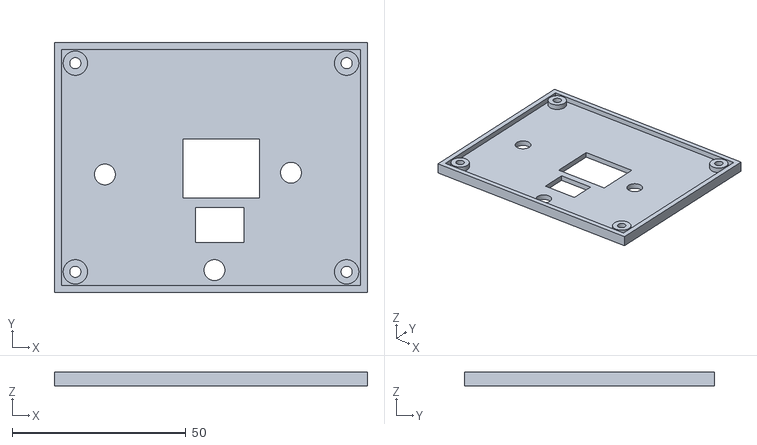
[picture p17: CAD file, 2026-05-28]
mechanical/supaclock_bottom_case.stl
90.0 x 72.0 x 4.00

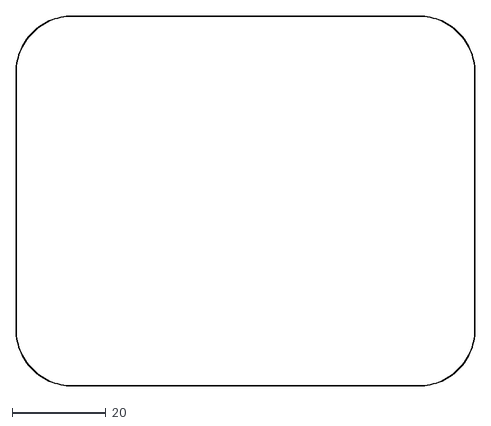
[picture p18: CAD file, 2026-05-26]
mechanical/dxf_sketches/bottom_outer.dxf
98.0 x 79.0

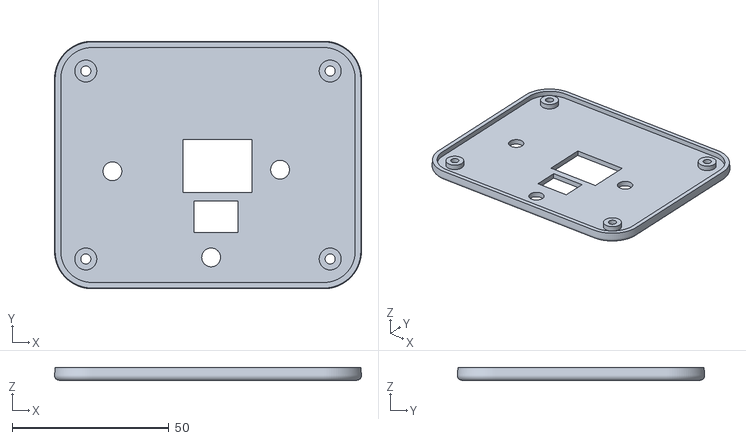
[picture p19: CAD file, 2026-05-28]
mechanical/supaclock_v2_bottom_case.stl
98.0 x 79.0 x 4.00

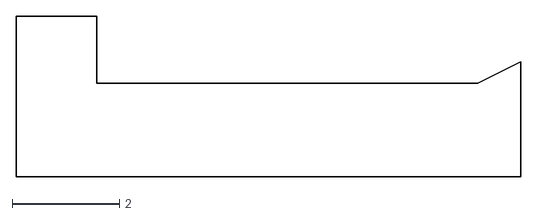
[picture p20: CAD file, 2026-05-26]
mechanical/dxf_sketches/button_cap.dxf
9.40 x 3.00

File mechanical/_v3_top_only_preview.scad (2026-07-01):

// Preview interior del top case (vista desde abajo, para ver tabs + costillas)
retention = "magnetic";
// Rotamos 180 sobre X y trasladamos +14 en Z para que la cara interior quede arriba
color([0.15, 0.15, 0.15])
    translate([0, 0, 14])
        rotate([180, 0, 0])
            import("stl_v3/supaclock_v3_top_magnetic.stl");

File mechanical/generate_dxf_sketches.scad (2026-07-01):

// =============================================================================
// SupaClock V2 - Generador de Croquis 2D en DXF para Fusion 360
//
// Este script genera los perfiles matemáticos 2D exactos para importarlos
// como Sketches (croquis) en Fusion 360 y realizar la modelación paramétrica
// (Método A + D).
//
// Uso desde la terminal:
// openscad -D "part=\"bottom_outer\"" -o dxf_sketches/bottom_outer.dxf generate_dxf_sketches.scad
// =============================================================================

$fn = 120; // Alta resolución para curvas suaves en CAD
part = "bottom_outer"; // Por defecto

// ---------------------------- PARAMETROS GLOBALES ----------------------------
W              = 98.0;
L              = 79.0;
r_vert         = 12.0;
taper          = 2.0;
grosor_pared   = 2.0;
pcb_off_x      = 6.5;
pcb_off_y      = 6.0;

// Parametros para insertos metalicos
use_inserts    = true;
insert_od      = 4.2;

// Posiciones PCB-locales trasladadas a case-locales
mh_positions = [
    [10.0, 69.5], // MH1
    [88.0, 69.5], // MH2
    [10.0,  9.5], // MH3
    [88.0,  9.5]  // MH4
];

pos_max30102 = [45.5 + pcb_off_x, 33.195 + pcb_off_y]; // (52.0, 39.195)
cut_max30102 = [17.0, 22.0];

pos_max30205 = [45.0 + pcb_off_x, 17.0 + pcb_off_y]; // (51.5, 23.0)
cut_max30205 = [14.0, 10.0];

electrode_positions = [
    [12.0 + pcb_off_x, 31.5 + pcb_off_y], // E1 (18.5, 37.5)
    [65.5 + pcb_off_x, 32.0 + pcb_off_y], // E2 (72.0, 38.0)
    [43.5 + pcb_off_x,  4.0 + pcb_off_y]  // E3 (50.0, 10.0)
];

display_center = [44.28 + pcb_off_x, 38.5 + pcb_off_y]; // (50.78, 44.5)
display_size   = [28.0, 34.0];

// Lugs
lug_thickness = 5.0;
lug_protrude  = 7.0;
y_inner       = 1.0;
y_case_edge   = 0.0;
y_outer_ctr   = -(lug_protrude - lug_thickness / 2); // -4.5

// Button Cap
flange_d = 6.0;
flange_h = 1.5;
stem_d   = 3.5;
stem_h   = 7.9;
lip_h    = 0.8;
lip_d    = 4.3;

// ----------------------------- MODULOS DE DIBUJO -----------------------------

module rounded_rect(w, l, r) {
    hull() {
        for (x = [r, w - r], y = [r, l - r]) {
            translate([x, y]) circle(r);
        }
    }
}

// 1. Perfil base exterior del bottom case (Z=0)
if (part == "bottom_outer") {
    rounded_rect(W, L, r_vert);
}

// 2. Perfil de la tapa superior exterior (Z=22) - Tapered
else if (part == "top_outer") {
    rounded_rect(W - 2 * taper, L - 2 * taper, r_vert - taper);
}

// 3. Perfil de la cavidad interna (Z=2)
else if (part == "inner_cavity") {
    rounded_rect(W - 2 * grosor_pared, L - 2 * grosor_pared, r_vert - grosor_pared);
}

// 4. Detalle del piso del bottom case (sensor cutouts + electrode holes + standoff centers)
else if (part == "bottom_cuts") {
    difference() {
        // Contorno de referencia de la cavidad (delgado)
        // (Sirve de guía en Fusion)
        %rounded_rect(W - 2 * grosor_pared, L - 2 * grosor_pared, r_vert - grosor_pared);

        // Ventana MAX30102
        translate(pos_max30102)
            square(cut_max30102, center = true);

        // Ventana MAX30205
        translate(pos_max30205)
            square(cut_max30205, center = true);

        // Orificios de electrodos (Ø6)
        for (pos = electrode_positions) {
            translate(pos) circle(d = 6.0);
        }

        // Puntos de centro de standoffs (círculos para inserto M3 o self-tap)
        for (pos = mh_positions) {
            translate(pos) circle(d = use_inserts ? insert_od : 2.7);
        }
    }
}

// 5. Detalle de la tapa del top case (display window + pillar centers)
else if (part == "top_cuts") {
    difference() {
        // Contorno de referencia superior tapered (delgado)
        %rounded_rect(W - 2 * taper, L - 2 * taper, r_vert - taper);

        // Ventana del display
        translate(display_center)
            square(display_size, center = true);

        // Agujeros de pilares (rosca M3 self-tap o inserto)
        for (pos = mh_positions) {
            translate(pos) circle(d = use_inserts ? insert_od : 2.7);
        }
    }
}

// 6. Perfil 2D de un Lug (para extrusión vertical en Fusion)
else if (part == "lug") {
    hull() {
        // Anclaje interior
        translate([-lug_thickness / 2, y_case_edge])
            square([lug_thickness, y_inner]);
        // Punta redondeada
        translate([0, y_outer_ctr])
            circle(d = lug_thickness);
    }
    // Agujero de spring bar (para verificar posición)
    %translate([0, y_outer_ctr])
        circle(d = 1.8);
}

// 7. Perfil de revolución del Button Cap (Z=axial, Y=radial)
else if (part == "button_cap") {
    union() {
        // Flange
        polygon([
            [0, 0],
            [flange_h, 0],
            [flange_h, flange_d / 2],
            [0, flange_d / 2]
        ]);
        // Stem
        polygon([
            [flange_h, 0],
            [flange_h + stem_h - lip_h, 0],
            [flange_h + stem_h - lip_h, stem_d / 2],
            [flange_h, stem_d / 2]
        ]);
        // Lip cónico
        polygon([
            [flange_h + stem_h - lip_h, 0],
            [flange_h + stem_h, 0],
            [flange_h + stem_h, lip_d / 2],
            [flange_h + stem_h - lip_h, stem_d / 2]
        ]);
    }
}

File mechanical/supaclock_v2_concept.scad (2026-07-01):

// =============================================================================
// SupaClock V2 CONCEPT - solo visual, no funcional
// Aplica 4 mejoras de estilizacion al envelope exterior:
//   (1) Esquinas verticales redondeadas r=10mm
//   (2) Chamfer top/bottom 1.5mm
//   (4) Lugs traseros para correa de 22mm + spring bar
//   (5) Wall taper de 1.5mm por lado (top mas angosto que bottom)
//
// NO incluye: cavidad interna, standoffs, pilares, cutouts de sensores en
// el piso, ni split bottom/top case. Es solo el envelope para visualizar
// la estetica.
// =============================================================================

$fn = 96;
eps = 0.01;

// ----------------------------- DIMENSIONES BASE ------------------------------
W = 90;             // ancho exterior (X) - mismo que V1
L = 71;             // largo exterior (Y) - mismo que V1
H = 25;             // alto total - mismo que V1 ensamblado

// ----------------------------- MEJORAS ---------------------------------------
r_vert    = 10.0;   // (1) radio de las esquinas verticales
r_chamfer = 1.5;    // (2) radio del chamfer superior e inferior
taper     = 1.5;    // (5) inset del top respecto del bottom (por lado)

// ----------------------------- LUGS (4) --------------------------------------
lug_strap_w   = 20.0;   // ancho de la correa (Galaxy Watch 4 = 20mm)
lug_thickness = 4.0;    // espesor del lug a lo largo de X
lug_protrude  = 7.0;    // cuanto sobresale el lug fuera del case
lug_z_top     = H - 3;  // top del lug (3mm bajo el techo)
lug_z_bot     = H - 13; // bottom del lug
spring_bar_d  = 1.8;    // agujero del spring bar (estandar 1.5mm + holgura)

// ----------------------------- DISPLAY ---------------------------------------
disp_w = 28;
disp_h = 34;
disp_cx = W / 2;
disp_cy = L / 2;

// ----------------------------- BOTONES + USB-C + JACK ------------------------
// Cotas tomadas de los SCADs V1 (PCB-local convertido a case-local W/L)
pcb_off_x = 2.5;
pcb_off_y = 2.5;
pcb_thickness = 1.6;
bottom_h = 4.0;             // altura del bottom case (4mm)

btn_y_pcb       = [15.375, 27.875];
btn_z_above_pcb = 1.9;
btn_hole_d      = 4.0;

usb_y_pcb       = 48.0;
usb_w_y         = 14.0;
usb_h_z         = 8.0;
usb_z_above_pcb = 13.0;

jack_x_pcb       = 13.525;
jack_d           = 7.5;
jack_z_above_pcb = 12.6;

// =============================================================================
// MODULOS
// =============================================================================

module outer_shell() {
    // Hull de 4 conos -> envelope rectangular con esquinas verticales redondas
    // y taper. Despues minkowski con esfera para chamfer top/bottom.
    minkowski() {
        hull() {
            for (x = [r_vert, W - r_vert], y = [r_vert, L - r_vert])
                translate([x, y, r_chamfer])
                    cylinder(h  = H - 2 * r_chamfer,
                             r1 = r_vert - r_chamfer,
                             r2 = r_vert - taper - r_chamfer);
        }
        sphere(r = r_chamfer);
    }
}

module lug_pair(y_base, dir_outward) {
    // dir_outward = -1 si y_base=0, +1 si y_base=L
    // Lug es un prisma con extremo redondeado, agujero transversal para
    // spring bar de Ø1.8mm
    lug_height = lug_z_top - lug_z_bot;

    for (xoff = [-lug_strap_w / 2, lug_strap_w / 2]) {
        x_center = W / 2 + xoff;
        y_outer  = y_base + dir_outward * lug_protrude;

        translate([x_center - lug_thickness / 2,
                   dir_outward == -1 ? y_outer : y_base,
                   lug_z_bot])
            difference() {
                hull() {
                    // Cuerpo recto pegado al case
                    cube([lug_thickness, lug_protrude * 0.6, lug_height]);
                    // Extremo redondeado
                    translate([lug_thickness / 2,
                               dir_outward == -1 ? 0 : lug_protrude - eps,
                               lug_height / 2])
                        rotate([90, 0, 0])
                            cylinder(h = eps, d = lug_height);
                }
                // Agujero para spring bar (a lo largo de X)
                translate([-eps,
                           dir_outward == -1
                               ? lug_protrude / 4
                               : lug_protrude * 3 / 4,
                           lug_height / 2])
                    rotate([0, 90, 0])
                        cylinder(h  = lug_thickness + 2 * eps,
                                 d  = spring_bar_d);
            }
    }
}

// =============================================================================
// CUTOUTS
// =============================================================================

module display_window() {
    translate([disp_cx - disp_w / 2, disp_cy - disp_h / 2, H - r_chamfer - 1])
        cube([disp_w, disp_h, r_chamfer + 2]);
}

module button_holes() {
    abs_z_offset = bottom_h + pcb_thickness;
    for (y_pcb = btn_y_pcb)
        translate([W - 5,
                   pcb_off_y + y_pcb,
                   abs_z_offset + btn_z_above_pcb])
            rotate([0, 90, 0])
                cylinder(h = 12, d = btn_hole_d, center = true);
}

module usb_cutout() {
    abs_z_offset = bottom_h + pcb_thickness;
    translate([W - 6,
               pcb_off_y + usb_y_pcb - usb_w_y / 2,
               abs_z_offset + usb_z_above_pcb - usb_h_z / 2])
        cube([12, usb_w_y, usb_h_z]);
}

module jack_cutout() {
    abs_z_offset = bottom_h + pcb_thickness;
    jack_y_abs = pcb_off_y + 16.586;

    translate([-3, jack_y_abs, abs_z_offset + jack_z_above_pcb])
        rotate([0, 90, 0])
            cylinder(h = 10, d = jack_d);

    translate([taper, jack_y_abs, abs_z_offset + jack_z_above_pcb])
        cylinder(h = H - (abs_z_offset + jack_z_above_pcb) + eps, d = jack_d);
}

// =============================================================================
// ENSAMBLE FINAL
// =============================================================================

difference() {
    union() {
        outer_shell();
        lug_pair(0, -1);   // lugs del lado -Y
        lug_pair(L, +1);   // lugs del lado +Y
    }

    display_window();
    button_holes();
    usb_cutout();
    jack_cutout();
}

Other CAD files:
mechanical/dxf_sketches/bottom_cuts.dxf
mechanical/stl_v3/supaclock_v3_face_sport_snap.stl
mechanical/supaclock_v4_assembly.scad
mechanical/stl/supaclock_v1_bottom_case.stl
mechanical/stl/supaclock_v1_top_case.stl
mechanical/stl/supaclock_v2_bottom_case.stl
mechanical/stl/supaclock_v2_button_caps.stl
mechanical/stl/supaclock_v2_top_case.stl
mechanical/stl_v3/supaclock_v3_bottom.stl
mechanical/stl_v3/supaclock_v3_face_classic_magnetic.stl
mechanical/stl_v3/supaclock_v3_face_classic_snap.stl
mechanical/stl_v3/supaclock_v3_face_minimal_magnetic.stl
mechanical/stl_v3/supaclock_v3_face_minimal_snap.stl
mechanical/stl_v3/supaclock_v3_face_sport_magnetic.stl
mechanical/stl_v3/supaclock_v3_top_magnetic.stl
mechanical/stl_v3/supaclock_v3_top_snap.stl
mechanical/supaclock_assembly.scad
mechanical/supaclock_bottom_case.scad
mechanical/supaclock_button_caps.scad
mechanical/supaclock_top_case.scad
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

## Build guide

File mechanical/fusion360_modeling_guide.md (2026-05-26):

# Guía Práctica de Modelado: SupaClock V2 en Fusion 360 (Método A + D)

Esta guía te guiará paso a paso para reconstruir de forma **profesional y paramétrica** la carcasa y los botones de SupaClock V2 en **Autodesk Fusion 360**, utilizando conjuntamente los planos técnicos generados y los perfiles vectoriales `.dxf` listos para usar en `mechanical/dxf_sketches/`.

---

## Recursos Generados en tu Carpeta `mechanical/`
1. **Plano de Ingeniería Industrial:** [supaclock_v2_blueprint.pdf](file:///home/articunot/Documents/PlatformIO/Projects/SupaClock/mechanical/supaclock_v2_blueprint.pdf) (Contiene 6 hojas con vistas ortográficas acotadas y secciones transversales).
2. **Perfiles Croquis 2D en DXF:** Ubicados en `mechanical/dxf_sketches/`:
   * `bottom_outer.dxf`: Contorno exterior del case en Z=0 (antes de chaflán, 98x79 mm, R12).
   * `top_outer.dxf`: Contorno exterior en Z=22 (tapered, 94x75 mm, R10).
   * `inner_cavity.dxf`: Contorno de la pared interna (94x75 mm, R10).
   * `bottom_cuts.dxf`: Ventanas de sensores, electrodos y centros de standoffs en el piso.
   * `top_cuts.dxf`: Ventana del display y pilares en el techo.
   * `lug.dxf`: Croquis 2D lateral de un lug para la correa de reloj.
   * `button_cap.dxf`: Sección transversal del botón lista para herramienta *Revolve* (Revolución).

---

## Flujo de Modelado en Fusion 360 (Paso a Paso)

### Paso 1: Configurar Parámetros del Proyecto (Método A - Paramétrico)
Antes de dibujar nada, define las variables globales para que puedas alterar las medidas en el futuro con un clic:
1. En la barra superior, ve a **Modify > Change Parameters** (Modificar > Cambiar parámetros).
2. Haz clic en el botón `+` e introduce los siguientes **User Parameters**:
   * `W = 98.0 mm` (Ancho total)
   * `L = 79.0 mm` (Largo total)
   * `H = 22.0 mm` (Altura total)
   * `taper = 2.0 mm` (Inclinación de las paredes)
   * `wall = 2.0 mm` (Grosor uniforme de pared)
   * `seam = 4.0 mm` (Plano de corte entre bottom y top case)

---

### Paso 2: Crear el Sólido Base Tapered (Afilado)
Utilizaremos los contornos DXF para crear la forma exterior estilizada:
1. **Perfil Base (Z=0):**
   * Haz clic en **Insert > Insert DXF** (Insertar > Insertar DXF).
   * Selecciona el plano **XY (horizontal)** y el archivo `bottom_outer.dxf`. Acepta.
2. **Plano de Altura:**
   * Ve a **Construct > Offset Plane** (Construir > Plano de desfase).
   * Selecciona el plano XY, y desplázalo hacia arriba a una distancia de `H` (22 mm).
3. **Perfil Superior (Z=22):**
   * Haz clic en **Insert > Insert DXF**.
   * Selecciona el plano de desfase que acabas de crear en Z=22, y elige el archivo `top_outer.dxf`.
4. **Loft (Solevantado):**
   * Ve a **Create > Loft** (Crear > Solevantar).
   * Selecciona el perfil del croquis inferior (Z=0) y el superior (Z=22).
   * Fusion creará un sólido de transición cónico perfecto con las esquinas redondeadas y el taper de 2mm.
5. **Chaflanes Horizontales:**
   * Ve a **Modify > Fillet** (o presiona la tecla `F`).
   * Selecciona la arista perimetral inferior (Z=0) y la superior (Z=22).
   * Aplica un filete/chaflán de **1.5 mm** para dar el acabado premium que se observa en los renders.

---

### Paso 3: Vaciado y Separación de Piezas
Ahora huecaremos el envelope y lo separaremos en Bottom Case y Top Case:
1. **Crear el Plano de Junta (Seam):**
   * Ve a **Construct > Offset Plane**, selecciona el plano XY (Z=0) e introduce la altura `seam` (4 mm).
2. **Vaciado de Paredes:**
   * Ve a **Modify > Shell** (Vaciado).
   * Selecciona la cara inferior del sólido (Z=0) y aplica un grosor de pared de `wall` (2 mm). Esto dejará la carcasa hueca y con paredes uniformes.
3. **Cortar la Carcasa:**
   * Ve a **Modify > Split Body** (Dividir cuerpo).
   * Selecciona el cuerpo de la carcasa como *Body to Split*.
   * Selecciona el plano de desfase Z=4 (plano de junta) como *Splitting Tool*.
   * Presiona OK. Ahora tendrás dos cuerpos independientes en tu línea de tiempo: **Bottom Case** (abajo, 4mm) y **Top Case** (arriba, 18mm).

---

### Paso 4: Detalles del Bottom Case (Agujeros e Implantes)
1. **Croquis de Detalles:**
   * Selecciona la cara interior plana del Bottom Case (Z = 2 mm).
   * Ve a **Insert > Insert DXF** y selecciona `bottom_cuts.dxf`.
2. **Ventanas de Sensores:**
   * Usa la herramienta **Extrude** (tecla `E`). Selecciona los rectángulos correspondientes a la ventana del sensor MAX30102 y MAX30205.
   * Extruye hacia abajo con la opción **Cut** (Cortar) atravesando el piso (Z=0).
3. **Agujeros de Electrodos:**
   * Selecciona los tres círculos de electrodos de Ø6mm y extruye hacia abajo en modo **Cut**.
4. **Standoffs (Pilares de soporte PCB):**
   * Crea un boceto en el piso interior (Z=2).
   * Dibuja 4 círculos concéntricos de Ø5.5 mm en los mismos centros provistos por los círculos de Ø2.7 mm en el DXF.
   * Extruye estos cilindros de Ø5.5 mm hacia **arriba** por `2.0 mm` (llegando a Z=4) con la operación **Join** (Unir) al Bottom Case.
   * Vuelve a activar el croquis DXF y extruye en modo **Cut** los círculos internos de Ø2.7 mm hacia abajo para dejar el canal roscado de los tornillos de fijación M3.

---

### Paso 5: Detalles del Top Case
1. **Ventana de Display:**
   * Selecciona la cara del techo interior del Top Case (Z = 20 mm).
   * Ve a **Insert > Insert DXF** y selecciona `top_cuts.dxf`.
   * Selecciona el rectángulo de la ventana de display (28x34 mm) y extruye hacia arriba en modo **Cut** atravesando el techo de 2mm (hasta Z=22).
2. **Pilares de Techo:**
   * Usando las referencias de centros de pilares provistas por `top_cuts.dxf`, dibuja círculos concéntricos de Ø5.5 mm.
   * Extrúyelos hacia **abajo** en modo **Join** hasta apoyar en el PCB (Z=5.6 en top-case-local). Haz un agujero concéntrico de Ø2.7 mm (rosca M3 self-tap).

---

### Paso 6: Agregar los Lugs de la Correa (Tapa Superior)
1. **Importar el Perfil Lateral del Lug:**
   * Crea un plano de desfase a la distancia lateral donde va el lug (`X = 35.5 mm`).
   * Selecciona ese plano e inserta `lug.dxf`.
   * El croquis contiene la silueta tipo "stadium" del lug.
2. **Extrusión y Agujero:**
   * Extruye la silueta por un grosor de `lug_thickness` (5.0 mm) hacia adentro del reloj.
   * Realiza una perforación transversal con **Modify > Hole** (Agujero) de Ø1.8 mm usando el centro del spring bar del DXF como referencia.
3. **Espejo (Mirror):**
   * Utiliza la herramienta **Create > Mirror** (Simetría) de tipo *Features* para duplicar el lug al otro extremo en el eje X, y luego haz simetría en el plano medio Y para tener los 4 lugs perfectos.

---

### Paso 7: Modelar los Botones en un Componente Aparte (Método D)
Para modelar los tapones físicos del botón:
1. Crea un nuevo componente (`New Component`) y llámalo "Button Cap".
2. Selecciona un plano de boceto vertical (plano XZ o YZ).
3. Ve a **Insert > Insert DXF** y selecciona `button_cap.dxf`.
4. Verás el perfil exacto de la mitad del botón en corte (flange Ø6, stem Ø3.5, y pestaña de retención cónica Ø4.3).
5. Ve a **Create > Revolve** (Revolución).
6. Selecciona el perfil cerrado del botón y elige la arista recta horizontal inferior (eje de simetría) como el **Axis**.
7. Fusion 360 generará instantáneamente un cuerpo cilíndrico de revolución perfecto del botón en 3D, sin necesidad de realizar extrusiones o chaflanes complicados.

---

¡Felicidades! Al utilizar esta metodología combinada, logras un diseño **100% editable e industrial** en menos de la mitad del tiempo tradicional.

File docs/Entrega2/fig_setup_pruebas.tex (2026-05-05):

\begin{tikzpicture}[
    node distance=1.2cm and 2.0cm,
    every node/.style={font=\scriptsize},
    dut/.style={rectangle, rounded corners, draw=black, very thick, fill=blue!18, text width=3.4cm, align=center, minimum height=1.2cm},
    inst/.style={rectangle, rounded corners, draw=black!70, very thick, fill=orange!22, text width=2.8cm, align=center, minimum height=0.95cm},
    soft/.style={rectangle, rounded corners, draw=black!70, very thick, fill=green!18, text width=2.8cm, align=center, minimum height=0.95cm},
    arrow/.style={->, >=stealth, thick}
]

% --- DUT central ---
\node[dut] (dut) {SupaClock\\(Seeed XIAO ESP32-S3\\+ PCB integrada)};

% --- Instrumentos / Fuentes ---
\node[inst, above=1.4cm of dut, xshift=-3.5cm] (oxm)  {Ox\'imetro cl\'inico\\(referencia HR/SpO\textsubscript{2})};
\node[inst, above=1.4cm of dut, xshift=3.5cm]  (term) {Term\'ometro IR\\(referencia $^\circ$C)};

% --- Logger / Software ---
\node[soft, below=1.4cm of dut, xshift=-3.5cm] (mon) {supaclock\_monitor.py\\(PC + plot + CSV)};
\node[soft, below=1.4cm of dut, xshift=3.5cm]  (app) {App Flutter Android\\(gateway BLE m\'ovil)};

% --- Conexiones ---
\draw[arrow] (oxm)  -- node[left, xshift=-0.1cm]{lado a lado} (dut.155);
\draw[arrow] (term) -- node[right, xshift=0.1cm]{contacto piel} (dut.25);

\draw[arrow, dashed, blue!60] (dut.-155) -- node[left]{BLE} (mon.north);
\draw[arrow, dashed, blue!60] (dut.-25)  -- node[right]{BLE} (app.north);

% --- Contenedor del set-up ---
\begin{scope}[on background layer]
\node[rectangle, draw=black!40, dashed, inner sep=0.6cm,
      fit=(oxm) (term) (mon) (app) (dut), fill=black!2] (lab) {};
\node[anchor=north west, font=\scriptsize\bfseries] at (lab.north west) {Set-up final de validaci\'on};
\end{scope}

\end{tikzpicture}

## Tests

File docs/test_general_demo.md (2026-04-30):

# SupaClock — `test_general` (Demo)

Documento de repaso para la demostración. Cubre el firmware corriendo en el
entorno `test_general` ([src/tests/test_general.c](../src/tests/test_general.c)),
que es la integración completa de todos los sensores, GUI, BLE y
power-management sobre un ESP32-C3.

---

## 1. Resumen ejecutivo

`test_general` enciende **todos** los subsistemas a la vez:

- **Display ST7789 240×280** con LVGL — UI con 5 pantallas cíclicas + 2
  sub-pantallas de configuración.
- **2 botones GPIO** (NEXT y SELECT) con detección short/long press.
- **5 sensores I2C/ADC**: BMI160 (IMU), MAX30102 (HR/SpO2), MAX30205 (temp),
  MAX17048 (fuel gauge), AD8232 (ECG por ADC continuo).
- **BLE NimBLE** con 4 características GATT (IMU, telemetría agregada,
  ECG streaming, comandos RX).
- **3 modos de energía** (SPORT/NORMAL/SAVER) que cambian cadencias de
  todos los sensores y del flush BLE; persistidos en NVS.
- **Light sleep dinámico** + PM locks para los caminos críticos.

El programa corre 7 tareas FreeRTOS coordinadas con dos mutexes.

---

## 2. Mapa de hardware (ESP32-C3)

| Periférico | Pin / Bus | Notas |
|---|---|---|
| I2C bus | configurado en `i2c_bus.c` | sensores: BMI160, MAX30102, MAX30205, MAX17048 |
| ST7789 SPI | configurado en `st7789.c` | 240×280, backlight por PWM |
| AD8232 OUT | ADC1 CH0 = **GPIO0** | modo continuous DMA |
| AD8232 SDN | GPIO 2 | encendido/apagado del front-end |
| Botón NEXT | GPIO 10 | pull-up interno, activo en bajo |
| Botón SELECT | GPIO 1 | pull-up + wakeup deep-sleep |

---

## 3. Arquitectura del firmware

### 3.1 Datos compartidos

Una sola estructura agrupa todas las lecturas; protegida por
`xSensorDataMutex`:

```c
typedef struct {
    int16_t  ax, ay, az, gx, gy, gz;     // IMU 6-DOF raw
    uint32_t steps_sw;                   // contador de pasos por SW
    float    temperature_c;
    uint16_t battery_mv;
    float    battery_soc;
    uint8_t  hr_bpm, spo2_pct;
    bool     finger_present;
    uint32_t hr_updated_ms, spo2_updated_ms,
             temp_updated_ms, bat_updated_ms;
} shared_sensor_data_t;
```

`xGuiSemaphore` protege a LVGL (no es thread-safe).

### 3.2 Tareas (FreeRTOS)

Todas se crean al final de `app_main`:

| Task | Prio | Stack | Frecuencia | Rol |
|---|---|---|---|---|
| `gui_task` | 5 | 4 KB | 30 Hz on / 10 Hz off | dibuja LVGL, lee botones, auto-off |
| `imu_task` | 6 | 4 KB | 50/25/12.5 Hz (modo) | BMI160 → pasos + jerk + BLE IMU |
| `hrm_task` | 5 | 4 KB | poll 10 Hz | MAX30102 (continuo o spot por modo) |
| `system_task` | 3 | 4 KB | cada 2 s | temperatura + batería |
| `ble_tx_task` | 4 | 4 KB | flush 1/10/60 s | flush del buffer agregado |
| `ecg_task` | 7 | 4 KB | bursts del DMA | AD8232 → BLE 0xFF03 |
| `perf_monitor_task` | 2 | 6 KB | cada 10 s | logs de heap, CPU, locks |

`ecg_task` es la **más prioritaria** (7) porque el DMA del ADC no espera; si
no se drena rápido, hay overruns.

### 3.3 Flujo general

```
              ┌──────────┐
   I2C   ───► │ sensors  │ ──► sensor_data (mutex)
              └──────────┘            │
                                       ▼
              ┌──────────┐         ┌─────────┐
   ADC  ───►  │ ecg_task │ ──BLE─► │ cliente │
              └──────────┘         └─────────┘
                                        ▲
              ┌──────────┐               │
   GPIO ───►  │ gui_task │ ── LVGL ──► ST7789
              └──────────┘
```

---

## 4. Modos de energía

Definidos en [lib/power_modes/power_modes.c](../lib/power_modes/power_modes.c).
El modo activo se persiste en NVS bajo `supaclock/power_mode`.

| Cadencia | SPORT | NORMAL | SAVER |
|---|---|---|---|
| HRM polling (FIFO) | 100 ms (continuo) | 100 ms (spot c/10 min) | 100 ms (spot c/30 min) |
| SpO2 automático | cada 5 min | cada 30 min | sólo manual |
| HRM SHDN entre medidas | no | sí | sí |
| IMU polling | 20 ms (50 Hz) | 40 ms (25 Hz) | 80 ms (12.5 Hz) |
| MAX30205 temp | 30 s | 5 min | 15 min |
| MAX17048 batería | 30 s | 30 s | 30 s |
| BLE agg flush | 1 s | 10 s | 60 s |
| Display auto-off default | 30 s | 15 s | 8 s |

Las tasks consultan `power_get_profile()` al inicio de cada iteración, así
un cambio de modo se aplica al próximo ciclo sin notificación explícita.

---

## 5. Display + UI (LVGL)

### 5.1 Pantallas

```c
typedef enum {
    SCREEN_HOME = 0,   // ciclables ─┐
    SCREEN_BIO,        //            │
    SCREEN_HRSPOT,     //            │ NEXT_SHORT recorre
    SCREEN_ECG,        //            │
    SCREEN_MENU,       //            ┘
    SCREEN_MODE,       // sub-screen, sólo desde MENU
    SCREEN_SETTINGS,   // sub-screen, sólo desde MENU
} ui_screen_t;
```

Build de cada pantalla: `build_home()`, `build_bio()`, `build_hrspot()`,
`build_ecg()`, `build_menu()`, `build_mode()`, `build_settings()`. Todas se
construyen una sola vez en `build_ui()`.

### 5.2 HOME

Reloj grande (mm:ss desde boot), línea con el modo activo, y 4 *cards*:
pasos, **arco de batería** (LVGL arc + label central), HR y actividad
(activo/reposo según magnitud del acelerómetro).

### 5.3 BIO

HR, SpO2, temperatura con *aging* relativo (`ahora`, `hace 12 s`, `hace 5 m`)
y un texto de "Estado" por color según el HR.

### 5.4 HRSPOT

Máquina de estados del SPOT del MAX30102:
`IDLE → SETTLING (5 s) → MEASURING → DONE / FAILED / ABORTED`.
Mostramos progreso porcentual, resultado y calidad (BUENA/REGULAR/POBRE).
SELECT inicia/cancela la medición.

### 5.5 ECG

- Estado **stop** → instrucciones.
- Estado **rec** → cronómetro mm:ss y badge "● REC".
- SELECT toggle del modo ECG (también lo puede activar el cliente BLE
  escribiendo `0x01` a la char de comandos 0xFF04).

### 5.6 MENU + sub-pantallas

Items del menú principal:

```
1. Modo Energia        → entra a MODE
2. Auto-off Pant.      → entra a SETTINGS
3. Reiniciar Pasos     → steps_sw = 0
4. Vincular BLE        → re-advertise (ya está activo siempre)
5. Apagar              → esp_deep_sleep_start, wake por SELECT
6. Tx IMU: ON/OFF      → toggle del envío IMU por BLE
7. Reset Bateria       → max17048_reset() (POR + Quick Start)
```

### 5.7 Botones — eventos

| Evento | En pantallas ciclables | En MENU/MODE/SETTINGS | En ECG / HRSPOT |
|---|---|---|---|
| NEXT short | siguiente pantalla | mover selección | — |
| NEXT long | pantalla anterior | volver a MENU | pantalla anterior |
| SELECT short | — | ejecutar/aplicar | start/stop/abort |
| SELECT long | volver a HOME | volver a HOME | volver a HOME |

### 5.8 Backlight & auto-off

`gui_task` cuenta inactividad por *décimas de frame* (~33 ms cada uno).
Al pasar `power_get_display_off_s(modo)` segundos sin botón, baja el PWM
del ST7789 a 0. Cualquier botón lo reenciende **sin disparar la acción**
del botón en sí (pulsación de "wake-up" no cuenta como input).

Cuando la pantalla está apagada, `gui_task` no ejecuta `lv_timer_handler()`
y baja a 10 Hz para ahorrar CPU.

---

## 6. Sensores

### 6.1 BMI160 — IMU + pasos + jerk

`imu_task` lee accel + giro a la cadencia del modo. Por iteración:

1. Lee 6 int16 (`bmi160_read_accel_gyro`).
2. Calcula **jerk** (`|Δaccel|²` escalado a 0–255) y se lo pasa al MAX30102
   (`max30102_set_motion_level`) — sirve de gate del HRM ante movimiento.
3. Llama al **algoritmo de pasos por SW** (`step_algo_update`), que detecta
   picos de magnitud sobre un umbral con histéresis y refractario.
4. Si está habilitado (item 6 del menú), envía 12 B raw por BLE 0xFF01.
5. Actualiza `sensor_data` (mutex).

> El step counter HW del BMI160 está deshabilitado a propósito (no irá en
> producción). Sólo se usa el algoritmo SW.

### 6.2 MAX30102 — HR/SpO2

Driver con dos modos de operación:

- **Continuous** (sólo SPORT): el sensor está siempre encendido, el FIFO
  se drena cada 100 ms, se publican TLV de HR cuando hay valor estable.
- **Spot** (NORMAL/SAVER): el sensor está apagado (`max30102_shutdown`),
  arranca cada `hrm_auto_period_ms`, hace SETTLING (5 s descartando) y
  luego MEASURING. Cuando termina, publica un TLV `SPOT_RESULT` y vuelve
  a apagarse.

El usuario puede iniciar un SPOT manual desde la pantalla HRSPOT
independiente del modo.

### 6.3 MAX30205 — temperatura

`system_task` lo lee cada `temp_period_ms` con `max30205_read_temperature`.
Publica TLV `TEMP` (i16 ×100 °C).

### 6.4 MAX17048 — fuel gauge

Driver: [lib/max17048_driver/max17048.c](../lib/max17048_driver/max17048.c).
Lee VCELL (mV) y SOC (% con fracción). Mejoras introducidas:

- **Detección de POR** en init: si el chip arrancó desde frío (bit RI=1
  del registro STATUS), ejecuta Quick Start para que la primera lectura
  parta del voltaje actual y no de un valor arbitrario.
- **Hibernate configurado** (HIBRT 0x80/0x30): bajo cargas pequeñas el
  ADC interno baja de 250 ms a 45 s, lo que reduce el ruido del SOC.
- **Reset por software** (`max17048_reset`) expuesto en el menú #7 — manda
  el comando POR (0x5400 → CMD reg 0xFE), encadena Quick Start y limpia
  el bit POR. Pensado para cuando se cambia la celda.
- **VRESET configurado** (umbral de detección "batería removida").

`system_task` publica TLV `BAT` cada 30 s (en todos los modos).

### 6.5 AD8232 — ECG (ADC continuous)

Front-end analógico con salida unipolar. La señal entra por GPIO0
(ADC1 CH0). El driver del ADC del IDF se configura en modo **continuous
DMA**:

- Frecuencia HW: **20 kHz** (mínimo en C3).
- Frame DMA: 1024 B → 256 muestras (`adc_digi_output_data_t` = 4 B).
- Buffer interno del DMA: 4096 B.
- Cada frame se notifica cada 256 / 20 000 ≈ **12.8 ms**.

`ad8232_init_dma` configura GPIOs (SDN, LO+/LO-) y prepara el DMA;
`ad8232_start_dma` / `ad8232_stop_dma` lo arrancan/detienen on-demand.

El detalle del flujo ECG está en la sección 8.

---

## 7. Bluetooth (NimBLE)

Implementación: [lib/ble_telemetry/ble_telemetry.c](../lib/ble_telemetry/ble_telemetry.c).

### 7.1 Servicio y características

Un único servicio primario `0xFF00` con cuatro características:

| UUID | Dir | Tipo | Contenido |
|---|---|---|---|
| `0xFF01` IMU | Read + Notify | binario | 12 B = 6 × i16 (ax,ay,az,gx,gy,gz) raw |
| `0xFF02` AGG | Read + Notify | TLV agregado | header + records (ver §7.3) |
| `0xFF03` ECG | Read + Notify | streaming | chunks de int16 (10 muestras = 20 B) |
| `0xFF04` CMD | Write | comandos RX | 1 B: 0x01=start ECG, 0x00=stop ECG |

El advertising publica **`SupaClock_BLE`** con appearance `0x00C1` (watch).
Intervalo de advertising: **1000 ms** (deliberadamente lento para permitir
light sleep entre eventos).

Sin pairing/bonding (compatibilidad con BlueZ y tests).

### 7.2 Camino directo vs. agregado

Hay dos maneras de mandar datos por BLE:

**Directo** — `ble_telemetry_send_imu()` y `ble_telemetry_send_ecg()`.
Llaman a `ble_gatts_notify_custom` inmediatamente. Se usan para flujos
de alta cadencia que no toleran agregación: IMU (50 Hz) y ECG (500 Hz).

**Agregado** — `ble_tx_push()` apila records TLV en un buffer
(`s_agg_buf`, máx 200 B). Cuando `ble_tx_task` llama a `ble_tx_flush()`
según la cadencia del modo (1/10/60 s), emite **un solo notify** con un
header + todos los records pendientes. Esto agrupa señales lentas
(HR, SpO2, temp, batería, eventos) y reduce drásticamente el costo
energético de la radio.

Si llega una señal de prioridad alta (resultado SPOT, cambio de modo) se
puede pasar `flush_now_mode != 0xFF` a `ble_tx_push()` para forzar el flush
inmediato sin esperar al timer.

### 7.3 Formato del paquete agregado (0xFF02)

```c
typedef struct __attribute__((packed)) {
    uint32_t boot_ts_ms;   // ms desde boot del primer record en el buffer
    uint8_t  power_mode;   // 0=SPORT 1=NORMAL 2=SAVER (al momento del flush)
    uint8_t  payload_len;  // bytes de records TLV que siguen
} ble_agg_header_t;

// payload: secuencia de records TLV
//   uint8_t  type;
//   uint8_t  len;
//   uint8_t  data[len];
```

Tipos definidos:

| Tipo | Bytes | Contenido |
|---|---|---|
| `0x01 HR` | 4 | u16 delta_ms, u8 bpm, u8 quality |
| `0x02 SPO2` | 4 | u16 delta_ms, u8 pct, u8 quality |
| `0x03 TEMP` | 4 | u16 delta_ms, i16 temp_x100 |
| `0x04 BAT` | 5 | u16 delta_ms, u16 mv, u8 soc |
| `0x05 STEPS` | 4 | u32 total_steps |
| `0x06 MODE_EVT` | 1 | u8 nuevo modo |
| `0x07 SPOT_RESULT` | 6 | u8 bpm, u8 spo2, u16 dur_ms, u8 quality, u8 aborted |

`delta_ms` se calcula relativo a `boot_ts_ms` del header → el cliente
reconstruye el timestamp absoluto sin necesidad de un reloj sincronizado.

### 7.4 Modo ECG (mutex implícito vs. agregado)

Cuando `ecg_mode_active = true`:

- `ble_telemetry_send_imu` se vuelve no-op (no compite con el ECG por la
  banda de la radio).
- `agg_emit_locked` descarta el contenido del buffer agregado.

Esto evita saturar la radio durante la grabación de ECG, que ya
domina el tráfico BLE.

---

## 8. ECG en detalle

`ecg_task` ([test_general.c:805](../src/tests/test_general.c#L805)):

```
HW continuous DMA @ 20 kHz
   │
   │ 256 muestras (4B × 256 = 1024 B) por frame  ─►  cada ~12.8 ms
   ▼
adc_continuous_read(dma_buf, 1024, ...)
   │
   │ por cada muestra del frame:
   │   sum += raw;  count++;
   │   if (count == 40) {
   │       chunk[i++] = sum / 40;     // promedio = boxcar antialias
   │       sum = 0; count = 0;
   │       if (i == 10) {
   │           ble_send_ecg(chunk);   // 10 × i16 = 20 B
   │       }
   │   }
   ▼
500 Hz efectivos al BLE  →  cliente plotea
```

- **Decimación 1:40 con promedio**: 20 kHz → 500 Hz. El boxcar (sum/40)
  actúa como filtro paso-bajo barato antes de bajar la frecuencia, y
  evita aliasing de armónicos altos.
- **Chunks de 10 int16**: ~20 ms de señal por notify, balance entre
  latencia y overhead BLE.

### 8.1 PM lock

`light_sleep_enable=true` está activo globalmente. Si el sistema se
duerme durante el DMA, al despertar el reloj del APB se reconfigura y la
señal del ADC muestra **escalones cuadrados** periódicos.

Solución: tomar un PM lock del tipo `ESP_PM_NO_LIGHT_SLEEP` mientras el
ADC continuo está corriendo:

```c
esp_pm_lock_create(ESP_PM_NO_LIGHT_SLEEP, 0, "ecg", &s_ecg_pm_lock);

// al iniciar:
esp_pm_lock_acquire(s_ecg_pm_lock);
ad8232_start_dma();

// al detener:
ad8232_stop_dma();
esp_pm_lock_release(s_ecg_pm_lock);
```

El lock sólo bloquea el light sleep — la radio sigue gestionando su
propio sleep entre intervals de conexión, y el DFS sigue libre.

---

## 9. Power management

### 9.1 Light sleep dinámico

```c
esp_pm_config_esp32c3_t pm_config = {
    .max_freq_mhz = 160,
    .min_freq_mhz = 10,
    .light_sleep_enable = true,
};
esp_pm_configure(&pm_config);
```

Esto activa **DFS (Dynamic Frequency Scaling)**: la CPU baja a 10 MHz
cuando está idle y entra a light sleep cuando todas las tasks están
bloqueadas. Drivers que necesitan reloj alto toman su propio lock
(I2C, SPI, ADC, NimBLE).

### 9.2 PM locks usados

- **ECG** (`ESP_PM_NO_LIGHT_SLEEP`) — sólo durante grabación.
- Internos del ADC continuo (APB max) — mientras el DMA corre.
- Internos de NimBLE — durante eventos de conexión.

`perf_monitor_task` puede dumpear los locks activos con
`esp_pm_dump_locks(stdout)` (necesita `CONFIG_PM_PROFILING`).

### 9.3 Deep sleep

El item "Apagar" del menú entra a **deep sleep** con wakeup por GPIO
(SELECT). Todo el RAM se pierde; el contador de pasos del BMI160 SW
también. Al despertar, vuelve a `app_main`.

---

## 10. Persistencia (NVS)

Namespace: `supaclock`. Claves:

| Clave | Tipo | Contenido |
|---|---|---|
| `power_mode` | u8 | modo activo (0=SPORT, 1=NORMAL, 2=SAVER) |
| `off_sport_s` | u16 | auto-off pantalla en SPORT |
| `off_normal_s` | u16 | auto-off pantalla en NORMAL |
| `off_saver_s` | u16 | auto-off pantalla en SAVER |

Nada más se persiste — pasos, batería, etc. se reinician en cada boot.

---

## 11. Pantalla por pantalla — guion de demo

| Paso | Acción | Mostrar |
|---|---|---|
| 1 | Encender (boot logs) | Detección de cada sensor en monitor serial |
| 2 | HOME | Reloj, modo SPORT, arco de batería real |
| 3 | NEXT_SHORT → BIO | HR/SpO2/temp con timestamps relativos |
| 4 | NEXT_SHORT → HRSPOT | SELECT inicia spot, ver progreso → resultado |
| 5 | NEXT_SHORT → ECG | SELECT empieza grabación, ver el ECG en el plotter Python |
| 6 | NEXT_SHORT → MENU | navegar items con NEXT, ejecutar con SELECT |
| 7 | Modo Energia → SPORT/NORMAL/SAVER | Cambian las cadencias, log lo confirma |
| 8 | Auto-off Pant. | Cambiar valor de auto-off del modo activo |
| 9 | Reset Bateria | El SOC se recalcula desde el voltaje actual |
| 10 | Apagar | Deep sleep; SELECT despierta de nuevo |

**Cliente BLE recomendado**: `tools/supaclock_monitor.py` (Python +
bleak). Se conecta a `SupaClock_BLE`, recibe los notify de las 4
características y plotea telemetría + ECG en vivo. Los CSV de ECG se
guardan en `tools/supaclock_ecg_*.csv`.

---

## 12. Glosario rápido de archivos

| Archivo | Qué hace |
|---|---|
| [src/tests/test_general.c](../src/tests/test_general.c) | El demo completo (este documento) |
| [lib/ble_telemetry/](../lib/ble_telemetry/) | Stack BLE NimBLE + GATT + buffer agregado |
| [lib/power_modes/](../lib/power_modes/) | Tabla de perfiles + persistencia NVS |
| [lib/ad8232_driver/](../lib/ad8232_driver/) | ADC continuous + GPIO control del front-end |
| [lib/max17048_driver/](../lib/max17048_driver/) | Fuel gauge — POR, Quick Start, hibernate |
| [lib/max30102_driver/](../lib/max30102_driver/) | HR/SpO2 con SM de SPOT |
| [lib/max30205_driver/](../lib/max30205_driver/) | Sensor de temperatura I2C |
| [lib/bmi160_driver/](../lib/bmi160_driver/) | Acelerómetro + giroscopio |
| [lib/step_algorithm/](../lib/step_algorithm/) | Pedómetro por SW (peak detection) |
| [lib/st7789_driver/](../lib/st7789_driver/) | Display SPI + brightness PWM |
| [lib/gpio_buttons/](../lib/gpio_buttons/) | Debounce + short/long press |
| [lib/i2c_bus/](../lib/i2c_bus/) | Bus compartido para los 4 sensores I2C |

---

## 13. Cosas a destacar en la demo

1. **Una sola tarea por dominio** — clarísima separación de responsabilidades.
2. **Doble camino BLE** (directo + agregado) — optimización energética
   real y medible.
3. **Modos de energía declarativos** — toda la cadencia en una tabla;
   las tasks la consultan, no requiere if/switch ni callbacks.
4. **PM lock para ECG** — solución correcta al problema del light sleep
   durante DMA, sin sacrificar ahorro energético en el resto del tiempo.
5. **MAX17048 con POR detection + hibernate** — fuel gauge "industrial",
   no hace reset destructivo en cada boot pero sí responde a una celda
   nueva.
6. **TLV con timestamp diferencial** — cliente reconstruye timeline sin
   necesidad de reloj sincronizado, ahorra bytes en cada record.

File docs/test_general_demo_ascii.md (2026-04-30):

# SupaClock -- `test_general` (Demo)

Documento de repaso para la demostracion. Cubre el firmware corriendo en el
entorno `test_general` ([src/tests/test_general.c](../src/tests/test_general.c)),
que es la integracion completa de todos los sensores, GUI, BLE y
power-management sobre un ESP32-C3.

---

## 1. Resumen ejecutivo

`test_general` enciende **todos** los subsistemas a la vez:

- **Display ST7789 240x280** con LVGL -- UI con 5 pantallas ciclicas + 2
  sub-pantallas de configuracion.
- **2 botones GPIO** (NEXT y SELECT) con deteccion short/long press.
- **5 sensores I2C/ADC**: BMI160 (IMU), MAX30102 (HR/SpO2), MAX30205 (temp),
  MAX17048 (fuel gauge), AD8232 (ECG por ADC continuo).
- **BLE NimBLE** con 4 caracteristicas GATT (IMU, telemetria agregada,
  ECG streaming, comandos RX).
- **3 modos de energia** (SPORT/NORMAL/SAVER) que cambian cadencias de
  todos los sensores y del flush BLE; persistidos en NVS.
- **Light sleep dinamico** + PM locks para los caminos criticos.

El programa corre 7 tareas FreeRTOS coordinadas con dos mutexes.

---

## 2. Mapa de hardware (ESP32-C3)

| Periferico | Pin / Bus | Notas |
|---|---|---|
| I2C bus | configurado en `i2c_bus.c` | sensores: BMI160, MAX30102, MAX30205, MAX17048 |
| ST7789 SPI | configurado en `st7789.c` | 240x280, backlight por PWM |
| AD8232 OUT | ADC1 CH0 = **GPIO0** | modo continuous DMA |
| AD8232 SDN | GPIO 2 | encendido/apagado del front-end |
| Boton NEXT | GPIO 10 | pull-up interno, activo en bajo |
| Boton SELECT | GPIO 1 | pull-up + wakeup deep-sleep |

---

## 3. Arquitectura del firmware

### 3.1 Datos compartidos

Una sola estructura agrupa todas las lecturas; protegida por
`xSensorDataMutex`:

```c
typedef struct {
    int16_t  ax, ay, az, gx, gy, gz;     // IMU 6-DOF raw
    uint32_t steps_sw;                   // contador de pasos por SW
    float    temperature_c;
    uint16_t battery_mv;
    float    battery_soc;
    uint8_t  hr_bpm, spo2_pct;
    bool     finger_present;
    uint32_t hr_updated_ms, spo2_updated_ms,
             temp_updated_ms, bat_updated_ms;
} shared_sensor_data_t;
```

`xGuiSemaphore` protege a LVGL (no es thread-safe).

### 3.2 Tareas (FreeRTOS)

Todas se crean al final de `app_main`:

| Task | Prio | Stack | Frecuencia | Rol |
|---|---|---|---|---|
| `gui_task` | 5 | 4 KB | 30 Hz on / 10 Hz off | dibuja LVGL, lee botones, auto-off |
| `imu_task` | 6 | 4 KB | 50/25/12.5 Hz (modo) | BMI160 -> pasos + jerk + BLE IMU |
| `hrm_task` | 5 | 4 KB | poll 10 Hz | MAX30102 (continuo o spot por modo) |
| `system_task` | 3 | 4 KB | cada 2 s | temperatura + bateria |
| `ble_tx_task` | 4 | 4 KB | flush 1/10/60 s | flush del buffer agregado |
| `ecg_task` | 7 | 4 KB | bursts del DMA | AD8232 -> BLE 0xFF03 |
| `perf_monitor_task` | 2 | 6 KB | cada 10 s | logs de heap, CPU, locks |

`ecg_task` es la **mas prioritaria** (7) porque el DMA del ADC no espera; si
no se drena rapido, hay overruns.

### 3.3 Flujo general

```
              +----------+
   I2C   ---> | sensors  | --> sensor_data (mutex)
              +----------+            |
                                       v
              +----------+         +---------+
   ADC  --->  | ecg_task | --BLE-> | cliente |
              +----------+         +---------+
                                        ^
              +----------+               |
   GPIO --->  | gui_task | -- LVGL --> ST7789
              +----------+
```

---

## 4. Modos de energia

Definidos en [lib/power_modes/power_modes.c](../lib/power_modes/power_modes.c).
El modo activo se persiste en NVS bajo `supaclock/power_mode`.

| Cadencia | SPORT | NORMAL | SAVER |
|---|---|---|---|
| HRM polling (FIFO) | 100 ms (continuo) | 100 ms (spot c/10 min) | 100 ms (spot c/30 min) |
| SpO2 automatico | cada 5 min | cada 30 min | solo manual |
| HRM SHDN entre medidas | no | si | si |
| IMU polling | 20 ms (50 Hz) | 40 ms (25 Hz) | 80 ms (12.5 Hz) |
| MAX30205 temp | 30 s | 5 min | 15 min |
| MAX17048 bateria | 30 s | 30 s | 30 s |
| BLE agg flush | 1 s | 10 s | 60 s |
| Display auto-off default | 30 s | 15 s | 8 s |

Las tasks consultan `power_get_profile()` al inicio de cada iteracion, asi
un cambio de modo se aplica al proximo ciclo sin notificacion explicita.

---

## 5. Display + UI (LVGL)

### 5.1 Pantallas

```c
typedef enum {
    SCREEN_HOME = 0,   // ciclables -+
    SCREEN_BIO,        //            |
    SCREEN_HRSPOT,     //            | NEXT_SHORT recorre
    SCREEN_ECG,        //            |
    SCREEN_MENU,       //            +
    SCREEN_MODE,       // sub-screen, solo desde MENU
    SCREEN_SETTINGS,   // sub-screen, solo desde MENU
} ui_screen_t;
```

Build de cada pantalla: `build_home()`, `build_bio()`, `build_hrspot()`,
`build_ecg()`, `build_menu()`, `build_mode()`, `build_settings()`. Todas se
construyen una sola vez en `build_ui()`.

### 5.2 HOME

Reloj grande (mm:ss desde boot), linea con el modo activo, y 4 *cards*:
pasos, **arco de bateria** (LVGL arc + label central), HR y actividad
(activo/reposo segun magnitud del acelerometro).

### 5.3 BIO

HR, SpO2, temperatura con *aging* relativo (`ahora`, `hace 12 s`, `hace 5 m`)
y un texto de "Estado" por color segun el HR.

### 5.4 HRSPOT

Maquina de estados del SPOT del MAX30102:
`IDLE -> SETTLING (5 s) -> MEASURING -> DONE / FAILED / ABORTED`.
Mostramos progreso porcentual, resultado y calidad (BUENA/REGULAR/POBRE).
SELECT inicia/cancela la medicion.

### 5.5 ECG

- Estado **stop** -> instrucciones.
- Estado **rec** -> cronometro mm:ss y badge "o REC".
- SELECT toggle del modo ECG (tambien lo puede activar el cliente BLE
  escribiendo `0x01` a la char de comandos 0xFF04).

### 5.6 MENU + sub-pantallas

Items del menu principal:

```
1. Modo Energia        -> entra a MODE
2. Auto-off Pant.      -> entra a SETTINGS
3. Reiniciar Pasos     -> steps_sw = 0
4. Vincular BLE        -> re-advertise (ya esta activo siempre)
5. Apagar              -> esp_deep_sleep_start, wake por SELECT
6. Tx IMU: ON/OFF      -> toggle del envio IMU por BLE
7. Reset Bateria       -> max17048_reset() (POR + Quick Start)
```

### 5.7 Botones -- eventos

| Evento | En pantallas ciclables | En MENU/MODE/SETTINGS | En ECG / HRSPOT |
|---|---|---|---|
| NEXT short | siguiente pantalla | mover seleccion | -- |
| NEXT long | pantalla anterior | volver a MENU | pantalla anterior |
| SELECT short | -- | ejecutar/aplicar | start/stop/abort |
| SELECT long | volver a HOME | volver a HOME | volver a HOME |

### 5.8 Backlight & auto-off

`gui_task` cuenta inactividad por *decimas de frame* (~33 ms cada uno).
Al pasar `power_get_display_off_s(modo)` segundos sin boton, baja el PWM
del ST7789 a 0. Cualquier boton lo reenciende **sin disparar la accion**
del boton en si (pulsacion de "wake-up" no cuenta como input).

Cuando la pantalla esta apagada, `gui_task` no ejecuta `lv_timer_handler()`
y baja a 10 Hz para ahorrar CPU.

---

## 6. Sensores

### 6.1 BMI160 -- IMU + pasos + jerk

`imu_task` lee accel + giro a la cadencia del modo. Por iteracion:

1. Lee 6 int16 (`bmi160_read_accel_gyro`).
2. Calcula **jerk** (`|?accel|2` escalado a 0-255) y se lo pasa al MAX30102
   (`max30102_set_motion_level`) -- sirve de gate del HRM ante movimiento.
3. Llama al **algoritmo de pasos por SW** (`step_algo_update`), que detecta
   picos de magnitud sobre un umbral con histeresis y refractario.
4. Si esta habilitado (item 6 del menu), envia 12 B raw por BLE 0xFF01.
5. Actualiza `sensor_data` (mutex).

> El step counter HW del BMI160 esta deshabilitado a proposito (no ira en
> produccion). Solo se usa el algoritmo SW.

### 6.2 MAX30102 -- HR/SpO2

Driver con dos modos de operacion:

- **Continuous** (solo SPORT): el sensor esta siempre encendido, el FIFO
  se drena cada 100 ms, se publican TLV de HR cuando hay valor estable.
- **Spot** (NORMAL/SAVER): el sensor esta apagado (`max30102_shutdown`),
  arranca cada `hrm_auto_period_ms`, hace SETTLING (5 s descartando) y
  luego MEASURING. Cuando termina, publica un TLV `SPOT_RESULT` y vuelve
  a apagarse.

El usuario puede iniciar un SPOT manual desde la pantalla HRSPOT
independiente del modo.

### 6.3 MAX30205 -- temperatura

`system_task` lo lee cada `temp_period_ms` con `max30205_read_temperature`.
Publica TLV `TEMP` (i16 x100 ?C).

### 6.4 MAX17048 -- fuel gauge

Driver: [lib/max17048_driver/max17048.c](../lib/max17048_driver/max17048.c).
Lee VCELL (mV) y SOC (% con fraccion). Mejoras introducidas:

- **Deteccion de POR** en init: si el chip arranco desde frio (bit RI=1
  del registro STATUS), ejecuta Quick Start para que la primera lectura
  parta del voltaje actual y no de un valor arbitrario.
- **Hibernate configurado** (HIBRT 0x80/0x30): bajo cargas pequenas el
  ADC interno baja de 250 ms a 45 s, lo que reduce el ruido del SOC.
- **Reset por software** (`max17048_reset`) expuesto en el menu #7 -- manda
  el comando POR (0x5400 -> CMD reg 0xFE), encadena Quick Start y limpia
  el bit POR. Pensado para cuando se cambia la celda.
- **VRESET configurado** (umbral de deteccion "bateria removida").

`system_task` publica TLV `BAT` cada 30 s (en todos los modos).

### 6.5 AD8232 -- ECG (ADC continuous)

Front-end analogico con salida unipolar. La senal entra por GPIO0
(ADC1 CH0). El driver del ADC del IDF se configura en modo **continuous
DMA**:

- Frecuencia HW: **20 kHz** (minimo en C3).
- Frame DMA: 1024 B -> 256 muestras (`adc_digi_output_data_t` = 4 B).
- Buffer interno del DMA: 4096 B.
- Cada frame se notifica cada 256 / 20 000 ~ **12.8 ms**.

`ad8232_init_dma` configura GPIOs (SDN, LO+/LO-) y prepara el DMA;
`ad8232_start_dma` / `ad8232_stop_dma` lo arrancan/detienen on-demand.

El detalle del flujo ECG esta en la seccion 8.

---

## 7. Bluetooth (NimBLE)

Implementacion: [lib/ble_telemetry/ble_telemetry.c](../lib/ble_telemetry/ble_telemetry.c).

### 7.1 Servicio y caracteristicas

Un unico servicio primario `0xFF00` con cuatro caracteristicas:

| UUID | Dir | Tipo | Contenido |
|---|---|---|---|
| `0xFF01` IMU | Read + Notify | binario | 12 B = 6 x i16 (ax,ay,az,gx,gy,gz) raw |
| `0xFF02` AGG | Read + Notify | TLV agregado | header + records (ver ?7.3) |
| `0xFF03` ECG | Read + Notify | streaming | chunks de int16 (10 muestras = 20 B) |
| `0xFF04` CMD | Write | comandos RX | 1 B: 0x01=start ECG, 0x00=stop ECG |

El advertising publica **`SupaClock_BLE`** con appearance `0x00C1` (watch).
Intervalo de advertising: **1000 ms** (deliberadamente lento para permitir
light sleep entre eventos).

Sin pairing/bonding (compatibilidad con BlueZ y tests).

### 7.2 Camino directo vs. agregado

Hay dos maneras de mandar datos por BLE:

**Directo** -- `ble_telemetry_send_imu()` y `ble_telemetry_send_ecg()`.
Llaman a `ble_gatts_notify_custom` inmediatamente. Se usan para flujos
de alta cadencia que no toleran agregacion: IMU (50 Hz) y ECG (500 Hz).

**Agregado** -- `ble_tx_push()` apila records TLV en un buffer
(`s_agg_buf`, max 200 B). Cuando `ble_tx_task` llama a `ble_tx_flush()`
segun la cadencia del modo (1/10/60 s), emite **un solo notify** con un
header + todos los records pendientes. Esto agrupa senales lentas
(HR, SpO2, temp, bateria, eventos) y reduce drasticamente el costo
energetico de la radio.

Si llega una senal de prioridad alta (resultado SPOT, cambio de modo) se
puede pasar `flush_now_mode != 0xFF` a `ble_tx_push()` para forzar el flush
inmediato sin esperar al timer.

### 7.3 Formato del paquete agregado (0xFF02)

```c
typedef struct __attribute__((packed)) {
    uint32_t boot_ts_ms;   // ms desde boot del primer record en el buffer
    uint8_t  power_mode;   // 0=SPORT 1=NORMAL 2=SAVER (al momento del flush)
    uint8_t  payload_len;  // bytes de records TLV que siguen
} ble_agg_header_t;

// payload: secuencia de records TLV
//   uint8_t  type;
//   uint8_t  len;
//   uint8_t  data[len];
```

Tipos definidos:

| Tipo | Bytes | Contenido |
|---|---|---|
| `0x01 HR` | 4 | u16 delta_ms, u8 bpm, u8 quality |
| `0x02 SPO2` | 4 | u16 delta_ms, u8 pct, u8 quality |
| `0x03 TEMP` | 4 | u16 delta_ms, i16 temp_x100 |
| `0x04 BAT` | 5 | u16 delta_ms, u16 mv, u8 soc |
| `0x05 STEPS` | 4 | u32 total_steps |
| `0x06 MODE_EVT` | 1 | u8 nuevo modo |
| `0x07 SPOT_RESULT` | 6 | u8 bpm, u8 spo2, u16 dur_ms, u8 quality, u8 aborted |

`delta_ms` se calcula relativo a `boot_ts_ms` del header -> el cliente
reconstruye el timestamp absoluto sin necesidad de un reloj sincronizado.

### 7.4 Modo ECG (mutex implicito vs. agregado)

Cuando `ecg_mode_active = true`:

- `ble_telemetry_send_imu` se vuelve no-op (no compite con el ECG por la
  banda de la radio).
- `agg_emit_locked` descarta el contenido del buffer agregado.

Esto evita saturar la radio durante la grabacion de ECG, que ya
domina el trafico BLE.

---

## 8. ECG en detalle

`ecg_task` ([test_general.c:805](../src/tests/test_general.c#L805)):

```
HW continuous DMA @ 20 kHz
   |
   | 256 muestras (4B x 256 = 1024 B) por frame  ->  cada ~12.8 ms
   v
adc_continuous_read(dma_buf, 1024, ...)
   |
   | por cada muestra del frame:
   |   sum += raw;  count++;
   |   if (count == 40) {
   |       chunk[i++] = sum / 40;     // promedio = boxcar antialias
   |       sum = 0; count = 0;
   |       if (i == 10) {
   |           ble_send_ecg(chunk);   // 10 x i16 = 20 B
   |       }
   |   }
   v
500 Hz efectivos al BLE  ->  cliente plotea
```

- **Decimacion 1:40 con promedio**: 20 kHz -> 500 Hz. El boxcar (sum/40)
  actua como filtro paso-bajo barato antes de bajar la frecuencia, y
  evita aliasing de armonicos altos.
- **Chunks de 10 int16**: ~20 ms de senal por notify, balance entre
  latencia y overhead BLE.

### 8.1 PM lock

`light_sleep_enable=true` esta activo globalmente. Si el sistema se
duerme durante el DMA, al despertar el reloj del APB se reconfigura y la
senal del ADC muestra **escalones cuadrados** periodicos.

Solucion: tomar un PM lock del tipo `ESP_PM_NO_LIGHT_SLEEP` mientras el
ADC continuo esta corriendo:

```c
esp_pm_lock_create(ESP_PM_NO_LIGHT_SLEEP, 0, "ecg", &s_ecg_pm_lock);

// al iniciar:
esp_pm_lock_acquire(s_ecg_pm_lock);
ad8232_start_dma();

// al detener:
ad8232_stop_dma();
esp_pm_lock_release(s_ecg_pm_lock);
```

El lock solo bloquea el light sleep -- la radio sigue gestionando su
propio sleep entre intervals de conexion, y el DFS sigue libre.

---

## 9. Power management

### 9.1 Light sleep dinamico

```c
esp_pm_config_esp32c3_t pm_config = {
    .max_freq_mhz = 160,
    .min_freq_mhz = 10,
    .light_sleep_enable = true,
};
esp_pm_configure(&pm_config);
```

Esto activa **DFS (Dynamic Frequency Scaling)**: la CPU baja a 10 MHz
cuando esta idle y entra a light sleep cuando todas las tasks estan
bloqueadas. Drivers que necesitan reloj alto toman su propio lock
(I2C, SPI, ADC, NimBLE).

### 9.2 PM locks usados

- **ECG** (`ESP_PM_NO_LIGHT_SLEEP`) -- solo durante grabacion.
- Internos del ADC continuo (APB max) -- mientras el DMA corre.
- Internos de NimBLE -- durante eventos de conexion.

`perf_monitor_task` puede dumpear los locks activos con
`esp_pm_dump_locks(stdout)` (necesita `CONFIG_PM_PROFILING`).

### 9.3 Deep sleep

El item "Apagar" del menu entra a **deep sleep** con wakeup por GPIO
(SELECT). Todo el RAM se pierde; el contador de pasos del BMI160 SW
tambien. Al despertar, vuelve a `app_main`.

---

## 10. Persistencia (NVS)

Namespace: `supaclock`. Claves:

| Clave | Tipo | Contenido |
|---|---|---|
| `power_mode` | u8 | modo activo (0=SPORT, 1=NORMAL, 2=SAVER) |
| `off_sport_s` | u16 | auto-off pantalla en SPORT |
| `off_normal_s` | u16 | auto-off pantalla en NORMAL |
| `off_saver_s` | u16 | auto-off pantalla en SAVER |

Nada mas se persiste -- pasos, bateria, etc. se reinician en cada boot.

---

## 11. Pantalla por pantalla -- guion de demo

| Paso | Accion | Mostrar |
|---|---|---|
| 1 | Encender (boot logs) | Deteccion de cada sensor en monitor serial |
| 2 | HOME | Reloj, modo SPORT, arco de bateria real |
| 3 | NEXT_SHORT -> BIO | HR/SpO2/temp con timestamps relativos |
| 4 | NEXT_SHORT -> HRSPOT | SELECT inicia spot, ver progreso -> resultado |
| 5 | NEXT_SHORT -> ECG | SELECT empieza grabacion, ver el ECG en el plotter Python |
| 6 | NEXT_SHORT -> MENU | navegar items con NEXT, ejecutar con SELECT |
| 7 | Modo Energia -> SPORT/NORMAL/SAVER | Cambian las cadencias, log lo confirma |
| 8 | Auto-off Pant. | Cambiar valor de auto-off del modo activo |
| 9 | Reset Bateria | El SOC se recalcula desde el voltaje actual |
| 10 | Apagar | Deep sleep; SELECT despierta de nuevo |

**Cliente BLE recomendado**: `tools/supaclock_monitor.py` (Python +
bleak). Se conecta a `SupaClock_BLE`, recibe los notify de las 4
caracteristicas y plotea telemetria + ECG en vivo. Los CSV de ECG se
guardan en `tools/supaclock_ecg_*.csv`.

---

## 12. Glosario rapido de archivos

| Archivo | Que hace |
|---|---|
| [src/tests/test_general.c](../src/tests/test_general.c) | El demo completo (este documento) |
| [lib/ble_telemetry/](../lib/ble_telemetry/) | Stack BLE NimBLE + GATT + buffer agregado |
| [lib/power_modes/](../lib/power_modes/) | Tabla de perfiles + persistencia NVS |
| [lib/ad8232_driver/](../lib/ad8232_driver/) | ADC continuous + GPIO control del front-end |
| [lib/max17048_driver/](../lib/max17048_driver/) | Fuel gauge -- POR, Quick Start, hibernate |
| [lib/max30102_driver/](../lib/max30102_driver/) | HR/SpO2 con SM de SPOT |
| [lib/max30205_driver/](../lib/max30205_driver/) | Sensor de temperatura I2C |
| [lib/bmi160_driver/](../lib/bmi160_driver/) | Acelerometro + giroscopio |
| [lib/step_algorithm/](../lib/step_algorithm/) | Pedometro por SW (peak detection) |
| [lib/st7789_driver/](../lib/st7789_driver/) | Display SPI + brightness PWM |
| [lib/gpio_buttons/](../lib/gpio_buttons/) | Debounce + short/long press |
| [lib/i2c_bus/](../lib/i2c_bus/) | Bus compartido para los 4 sensores I2C |

---

## 13. Cosas a destacar en la demo

1. **Una sola tarea por dominio** -- clarisima separacion de responsabilidades.
2. **Doble camino BLE** (directo + agregado) -- optimizacion energetica
   real y medible.
3. **Modos de energia declarativos** -- toda la cadencia en una tabla;
   las tasks la consultan, no requiere if/switch ni callbacks.
4. **PM lock para ECG** -- solucion correcta al problema del light sleep
   durante DMA, sin sacrificar ahorro energetico en el resto del tiempo.
5. **MAX17048 con POR detection + hibernate** -- fuel gauge "industrial",
   no hace reset destructivo en cada boot pero si responde a una celda
   nueva.
6. **TLV con timestamp diferencial** -- cliente reconstruye timeline sin
   necesidad de reloj sincronizado, ahorra bytes en cada record.

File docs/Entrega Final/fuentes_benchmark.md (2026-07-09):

# Fuentes y benchmarks para la presentación final

Consulta realizada el 2026-07-08.

## Fuentes locales del proyecto

- `docs/Entrega3/presentacion3.tex`
- `docs/Entrega4/presentacion4.tex`
- `docs/Entrega4/guion_15min.md`
- `docs/ble_har_protocol.md`
- `app/ble_har_protocol.md`
- `app/firmware_handoff_har.md`
- `data_ml/PLAN_MUESTRAS.md`
- `mechanical/supaclock_v3_dimensions.md`
- `mechanical/supaclock_v4_*.scad`
- `lib/power_modes/power_modes.c`
- `app/lib/services/ble_service.dart`

## Benchmarks externos propuestos

- Apple Watch Compare — referencia de experiencia integrada, ECG, SpO₂, temperatura y autonomía comercial:
  https://www.apple.com/watch/compare/

- Garmin Venu 4 — referencia de smartwatch deportivo y autonomía comercial:
  https://www.garmin.com/en-US/p/1614061/

- Garmin Support — Pulse Ox como referencia de función de oximetría en smartwatch:
  https://support.garmin.com/

- Beurer PO30 — referencia propuesta para spot-check BPM/SpO₂:
  https://www.beurer.com/

- Beurer ME36/ME80 u otro ECG portátil disponible en laboratorio — referencia propuesta para ECG de reposo:
  https://www.beurer.com/

## Criterios de validación sugeridos

- BPM: error medio y máximo frente a oxímetro/banda de referencia.
- SpO₂: desviación porcentual frente a oxímetro de dedo.
- Temperatura: error absoluto frente a termómetro de contacto.
- Pasos: error relativo frente a conteo manual en 50, 100 y 500 pasos.
- ECG: forma de onda, ruido, detección de R-peaks y repetibilidad con usuario en reposo.
- Autonomía: curva real de descarga medida con MAX17048 hasta apagado/protección.

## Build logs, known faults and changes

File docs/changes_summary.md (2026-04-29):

# Historial de Cambios: Optimización Energética de SupaClock

Este documento resume todas las modificaciones realizadas en el firmware para solucionar los bloqueos (`Power Manager Locks`) que impedían al ESP32-C3 entrar en *Light Sleep*, manteniendo la CPU a 80 MHz (APB_MAX) casi el 100% del tiempo.

## 1. Liberación del bloqueo DMA del ECG (`adc_dma`)
**Problema:** Al llamar a `ad8232_init_dma()` en el `app_main`, se creaba el handle del ADC Continuo (`adc_continuous_new_handle`). En ESP-IDF, la mera existencia de este handle registra un bloqueo estricto en el bus APB (`APB_FREQ_MAX`) para garantizar la estabilidad de reloj durante las transferencias DMA, incluso si el ADC no está corriendo.
**Solución:** 
Se modificó `lib/ad8232_driver/ad8232.c`:
*   Se eliminó la inicialización del handle en `ad8232_init_dma()`.
*   Se movió `adc_continuous_new_handle()` y `adc_continuous_config()` al interior de `ad8232_start_dma()`.
*   Se añadió `adc_continuous_deinit()` dentro de `ad8232_stop_dma()`.
*   **Resultado:** El bloqueo sobre el APB ahora se adquiere **solo** cuando el usuario entra explícitamente a la pantalla del ECG y se libera completamente al salir.

## 2. Implementación de Toggle UI para IMU
**Problema:** El envío constante de datos IMU vía BLE (a 50 Hz en modo SPORT) impedía que la radio Bluetooth entrara en reposo entre transmisiones.
**Solución:** 
Se modificó `src/tests/test_general.c`:
*   Se añadió la variable global `static bool imu_ble_tx_enabled = true;`.
*   Se expandió el menú de la GUI (`MENU_ITEM_COUNT` de 5 a 6) añadiendo `"Tx IMU: ON"`.
*   Se reajustó el padding dinámico de las celdas del menú para que la nueva opción encajara perfectamente en la resolución de 240x280.
*   En `menu_execute_selected()`, se añadió la lógica del toggle.
*   En `imu_task`, se envolvió la función `ble_telemetry_send_imu(imu_raw, sizeof(imu_raw));` con un `if (imu_ble_tx_enabled)`. Así, los cálculos locales (podómetro, *jerk*) siguen corriendo, pero la radio puede descansar.

## 3. Relajación del Advertising BLE
**Problema:** La configuración original iniciaba el *advertising* (`ble_gap_adv_start`) con parámetros por defecto. NimBLE usa un intervalo muy agresivo (~30 ms) que deja márgenes ínfimos para que el Sistema Operativo duerma al chip.
**Solución:** 
Se modificó `lib/ble_telemetry/ble_telemetry.c`:
*   Se forzó el intervalo de *advertising* a 1000 milisegundos.
*   `adv_params.itvl_min = 1600; /* 1600 * 0.625ms = 1000ms */`
*   `adv_params.itvl_max = 1600;`

## 4. Habilitación del Modem Sleep en Bluetooth
**Problema:** A pesar de los arreglos anteriores, la radio (`bt` y `btLS`) adquiría el bloqueo `NO_LIGHT_SLEEP` en el arranque y nunca lo soltaba (`Total_count: 1`, `Active: 1`). Esto se debe a que el ESP-IDF requiere instrucciones explícitas para permitir apagar el módem y confiar en el cristal principal.
**Solución:** 
Se modificó `sdkconfig.defaults`:
*   Se añadieron los siguientes flags para forzar al controlador Bluetooth a delegar el reloj de sueño y permitir el *Light Sleep*:
```ini
CONFIG_BT_CTRL_MODEM_SLEEP=y
CONFIG_BT_CTRL_MODEM_SLEEP_MODE_1=y
CONFIG_BT_CTRL_MAIN_XTAL_PU_DURING_LIGHT_SLEEP=y
```
*(Nota: tras este cambio se requirió limpiar la compilación para que el framework inyectara las nuevas directivas al sdkconfig generado).*

## 5. Resultados Finales y Comparativa
Tras aplicar todas las mitigaciones conjuntas, el sistema experimentó una mejora drástica en la gestión energética, evidenciada por los logs del sistema:

### Antes de la Optimización (Problema Original)
*   **Modo SLEEP:** 0 % (No dormía nunca).
*   **Modo APB_MAX (80 MHz):** 92 % del tiempo.
*   **Causa:** El handle del DMA del ADC retenía estáticamente la frecuencia, y el módem Bluetooth carecía de permisos para apagarse o delegar su reloj al cristal principal.

### Después de la Optimización (Solución Aplicada)
*   **Modo SLEEP:** 75 % del tiempo.
*   **Modo APB_MAX (80 MHz):** Reducido al 15 %.
*   **Modo CPU_MAX (160 MHz):** ~9 % (Manejado dinámicamente por ráfagas computacionales de LVGL y sensores).

> [!TIP]
> **¿Por qué activar/desactivar la transmisión del IMU ya no afecta apenas al porcentaje de Sleep estando conectados?**
> Al habilitar el "Modem Sleep" en el punto 4, el controlador BLE ahora es inteligente. Aunque le inyectemos lecturas del IMU a 50Hz (IMU_TX = ON), NimBLE simplemente encola esos datos en su buffer interno y despierta la radio **únicamente** cuando toca el evento de conexión dictado por el "Connection Interval" del cliente (ej. cada 30ms o 45ms). Al transmitir todo el paquete acumulado en ráfaga, la radio vuelve a dormir inmediatamente, logrando ese ~75% de eficiencia térmica y energética en ambos casos.

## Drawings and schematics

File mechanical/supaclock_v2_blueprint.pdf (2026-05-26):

## VISTA EN PLANTA - BOTTOM CASE (mirando hacia -Z)

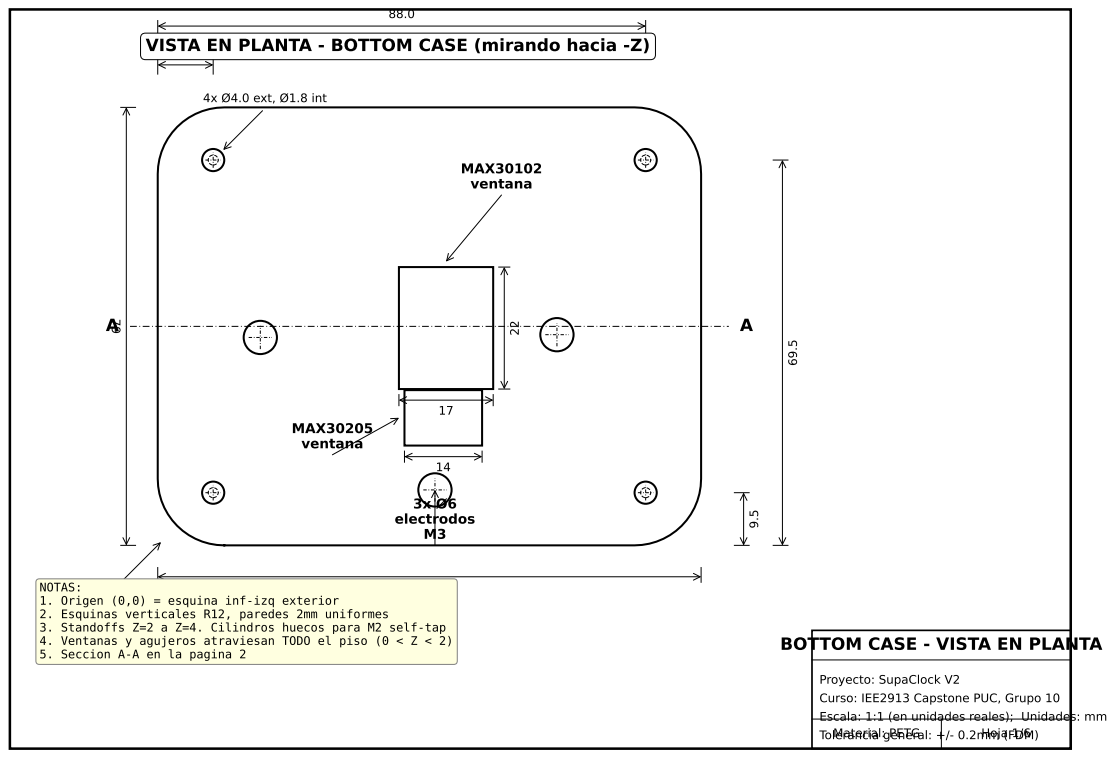
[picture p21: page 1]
Tolerancia general: +/- 0.2mm (FDM) Material: PETG; Hoja 1/6; 4x Ø4.0 ext, Ø1.8 int; MAX30102 ventana; MAX30205 ventana; 3x Ø6 electrodos M3

NOTAS:
1. Origen (0,0) = esquina inf-izq exterior
2. Esquinas verticales R12, paredes 2mm uniformes
3. Standoffs Z=2 a Z=4. Cilindros huecos para M2 self-tap
4. Ventanas y agujeros atraviesan TODO el piso (0 < Z < 2)
5. Seccion A-A en la pagina 2

BOTTOM CASE - VISTA EN PLANTA

Proyecto: SupaClock V2
Curso: IEE2913 Capstone PUC, Grupo 10
Escala: 1:1 (en unidades reales); Unidades: mm

## SECCION A-A (corte horizontal Y=39.5 = L/2)

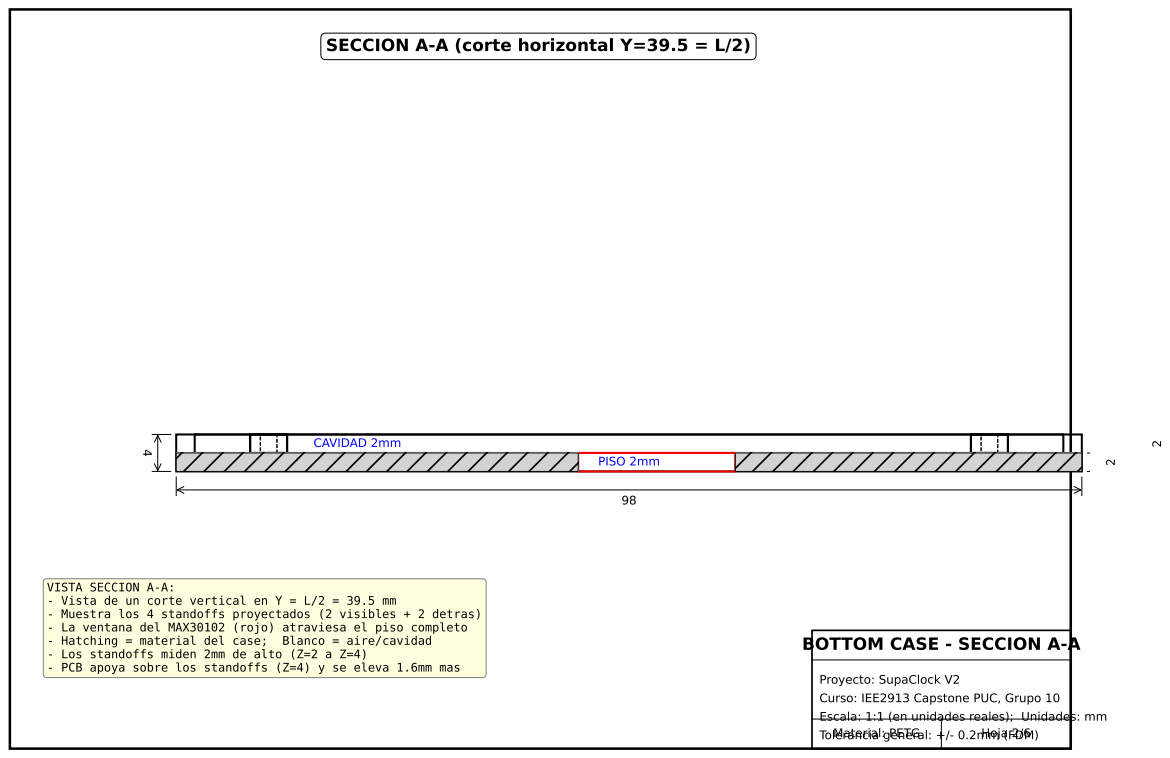
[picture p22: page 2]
Tolerancia general: +/- 0.2mm (FDM) Material: PETG; Hoja 2/6; - Hatching = material del case;; Blanco = aire/cavidad

CAVIDAD 2mm

PISO 2mm

VISTA SECCION A-A:
- Vista de un corte vertical en Y = L/2 = 39.5 mm
- Muestra los 4 standoffs proyectados (2 visibles + 2 detras)
- La ventana del MAX30102 (rojo) atraviesa el piso completo
- Los standoffs miden 2mm de alto (Z=2 a Z=4)
- PCB apoya sobre los standoffs (Z=4) y se eleva 1.6mm mas

BOTTOM CASE - SECCION A-A

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

## TOP CASE - PLANTA

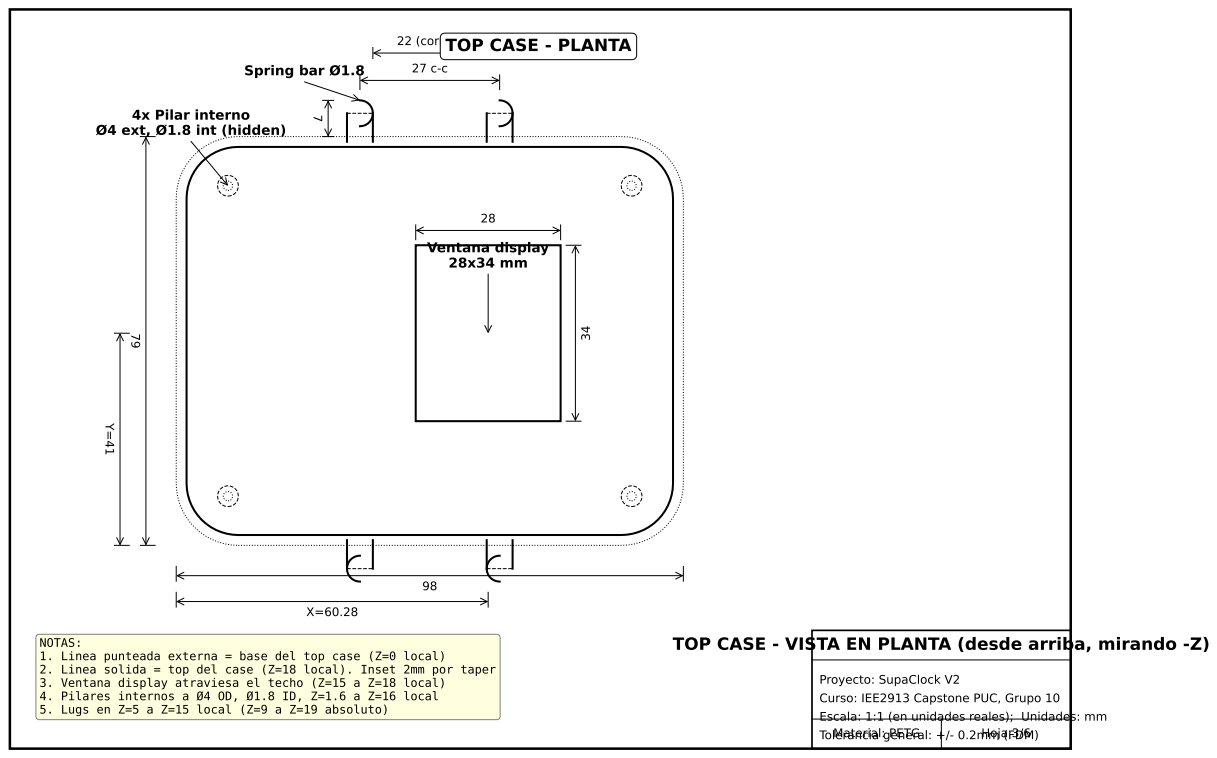
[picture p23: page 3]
Tolerancia general: +/- 0.2mm (FDM) Material: PETG; Hoja 3/6; Ventana display 28x34 mm; 22 (correa); Spring bar Ø1.8

4x Pilar interno
Ø4 ext, Ø1.8 int (hidden)

NOTAS:
1. Linea punteada externa = base del top case (Z=0 local)
2. Linea solida = top del case (Z=18 local). Inset 2mm por taper
3. Ventana display atraviesa el techo (Z=15 a Z=18 local)
4. Pilares internos a Ø4 OD, Ø1.8 ID, Z=1.6 a Z=16 local
5. Lugs en Z=5 a Z=15 local (Z=9 a Z=19 absoluto)

TOP CASE - VISTA EN PLANTA (desde arriba, mirando -Z)

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

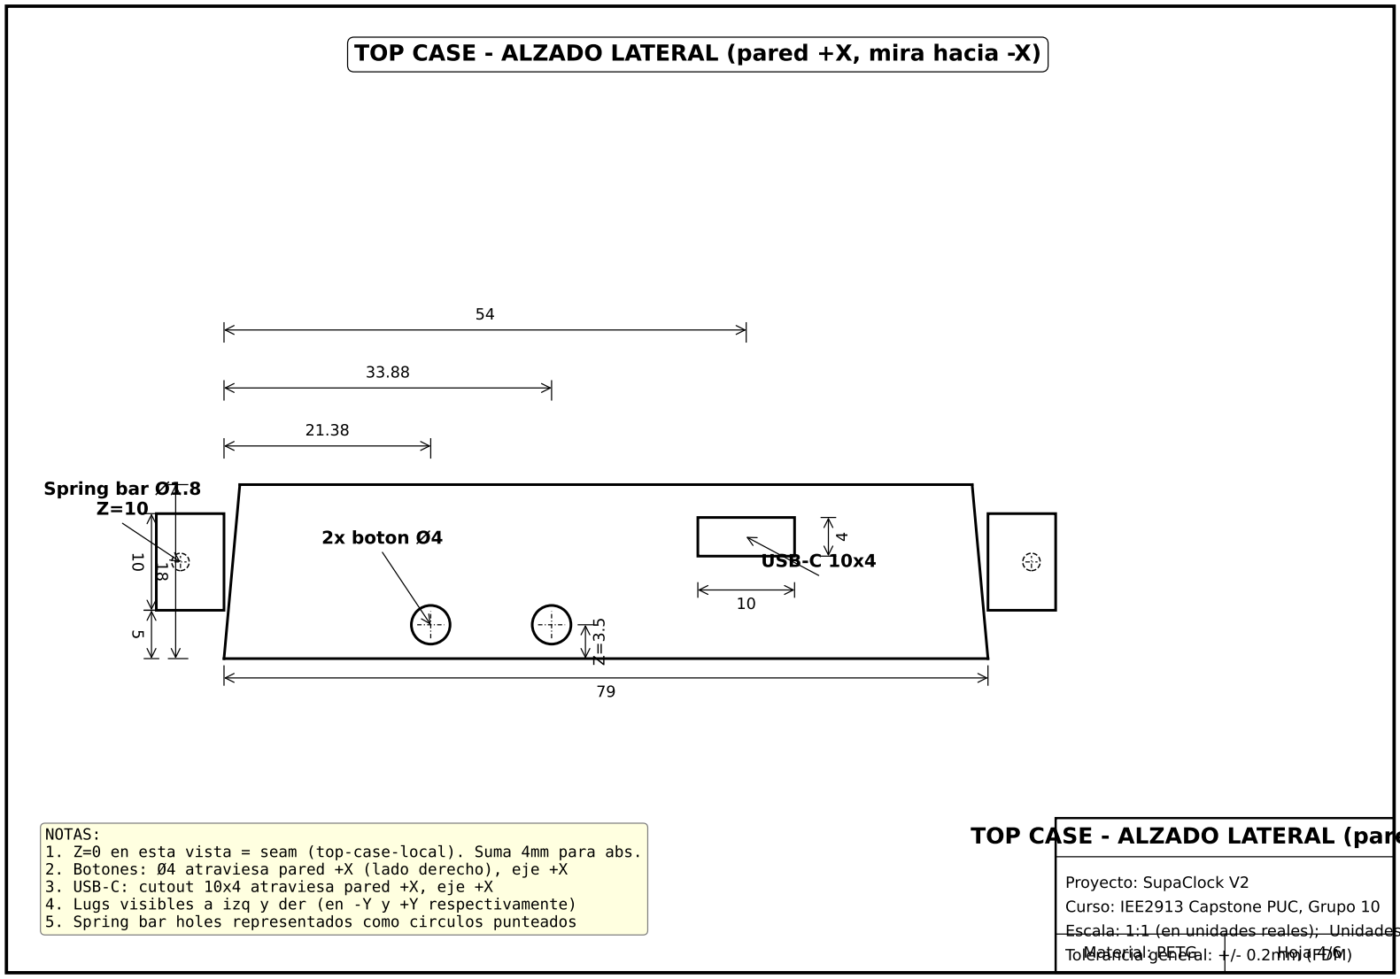
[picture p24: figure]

## TOP CASE - ALZADO FRONTAL (mira hacia +Y)

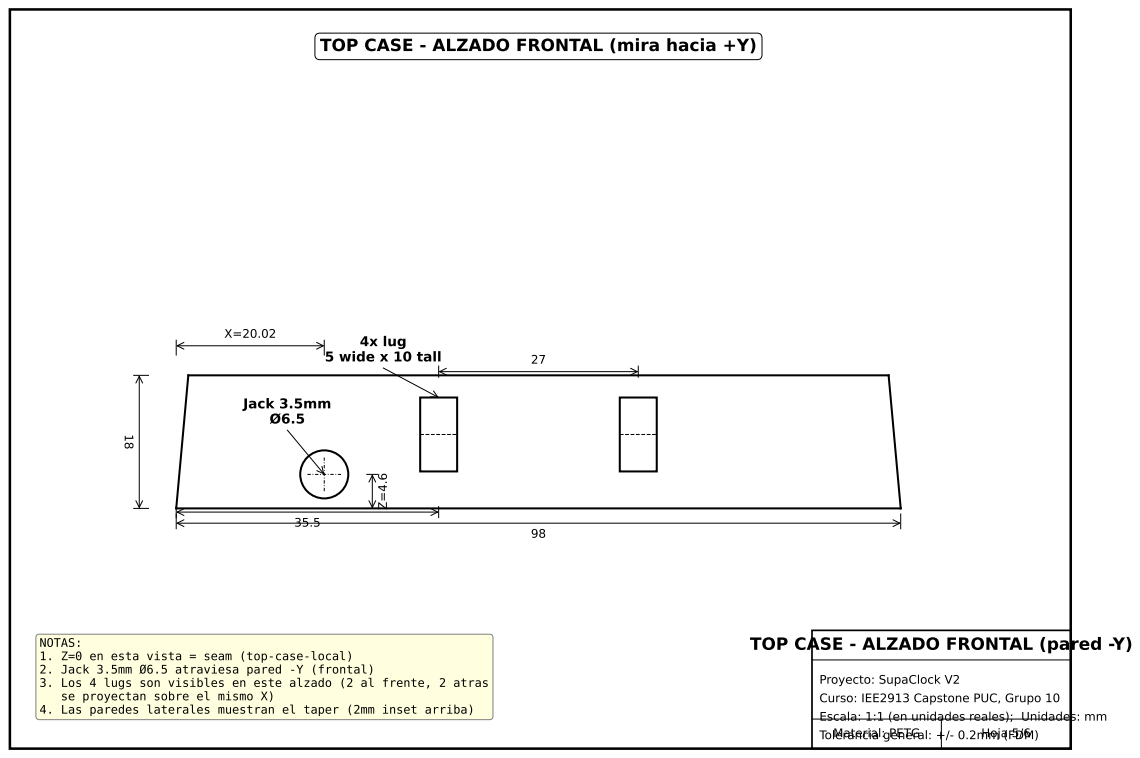
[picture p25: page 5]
Tolerancia general: +/- 0.2mm (FDM) Material: PETG; Hoja 5/6; Jack 3.5mm Ø6.5; 4x lug 5 wide x 10 tall

NOTAS:
1. Z=0 en esta vista = seam (top-case-local)
2. Jack 3.5mm Ø6.5 atraviesa pared -Y (frontal)
3. Los 4 lugs son visibles en este alzado (2 al frente, 2 atras
se proyectan sobre el mismo X)
4. Las paredes laterales muestran el taper (2mm inset arriba)

TOP CASE - ALZADO FRONTAL (pared -Y)

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

## DETALLE LUG (vista en planta, escala 7x) ¹⁰

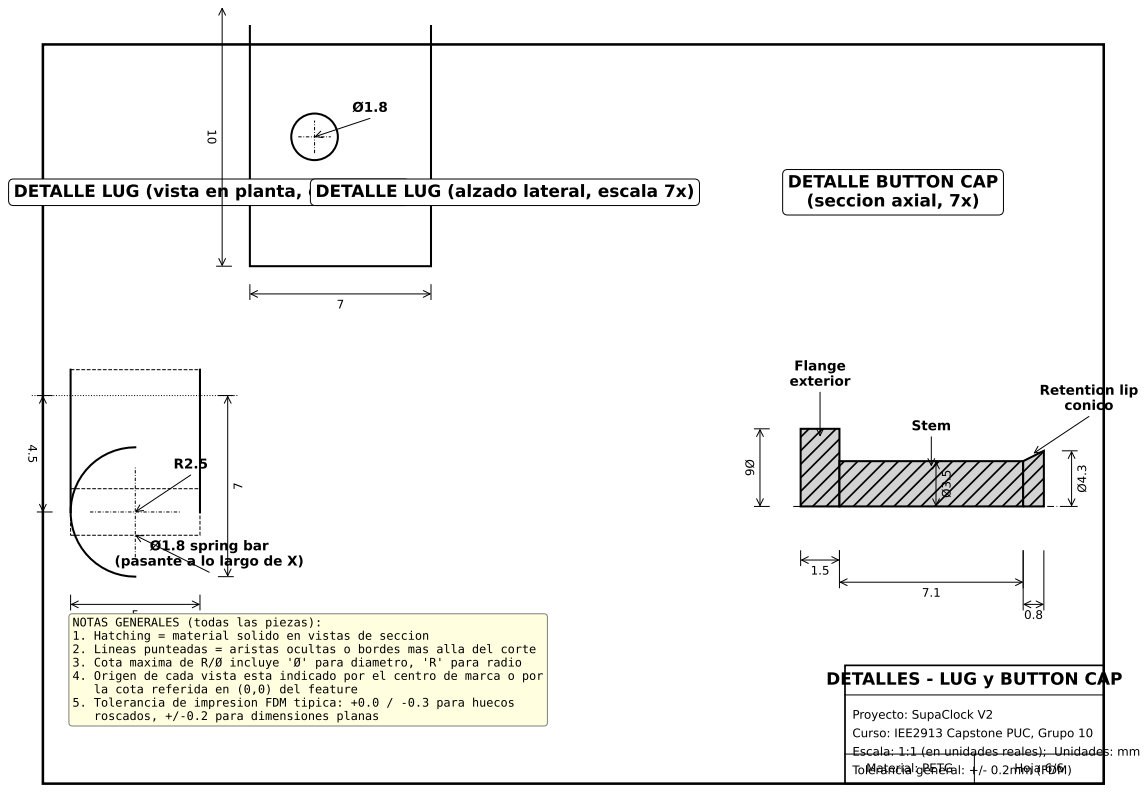
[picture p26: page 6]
Tolerancia general: +/- 0.2mm (FDM) Material: PETG; Hoja 6/6; Flange exterior; Stem; Retention lip conico

DETALLE BUTTON CAP
(seccion axial, 7x)

DETALLE LUG (alzado lateral, escala 7x)

Ø1.8 spring bar
(pasante a lo largo de X)

NOTAS GENERALES (todas las piezas):
1. Hatching = material solido en vistas de seccion
2. Lineas punteadas = aristas ocultas o bordes mas alla del corte
3. Cota maxima de R/Ø incluye 'Ø' para diametro, 'R' para radio
4. Origen de cada vista esta indicado por el centro de marca o por
la cota referida en (0,0) del feature
5. Tolerancia de impresion FDM tipica: +0.0 / -0.3 para huecos
roscados, +/-0.2 para dimensiones planas

DETALLES - LUG y BUTTON CAP

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

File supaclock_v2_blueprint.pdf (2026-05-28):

## VISTA EN PLANTA - BOTTOM CASE (mirando hacia -Z)

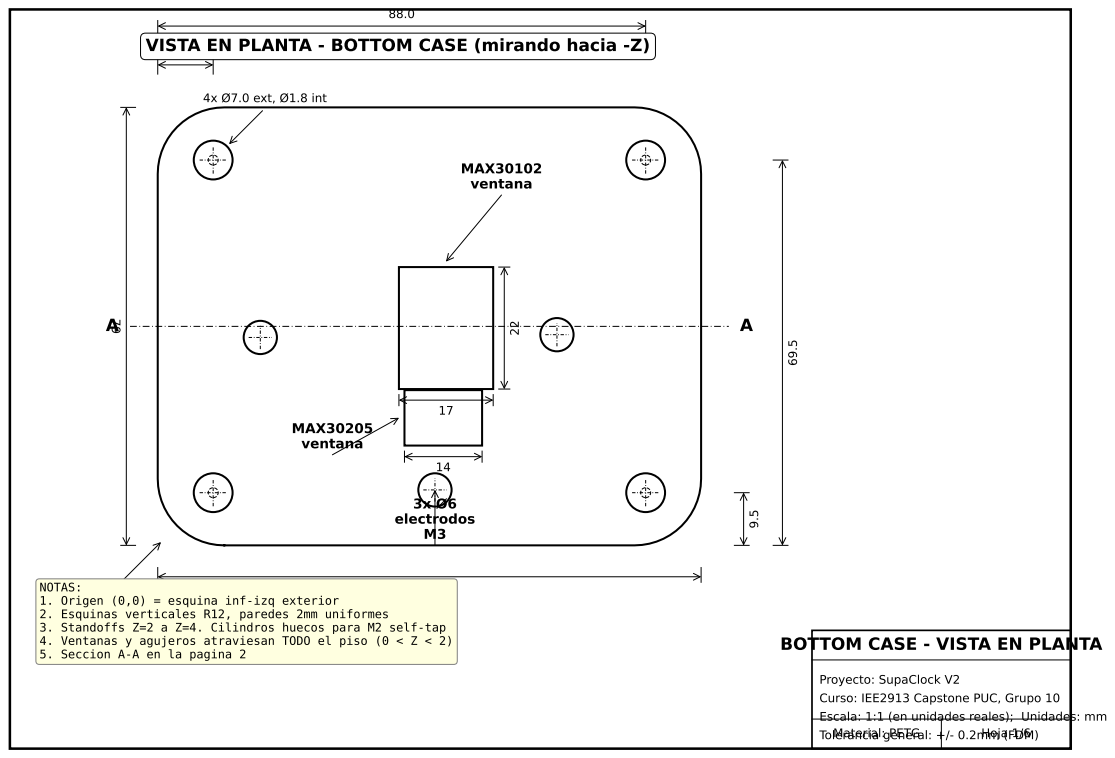
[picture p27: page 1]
Tolerancia general: +/- 0.2mm (FDM) Material: PETG; Hoja 1/6; 4x Ø7.0 ext, Ø1.8 int; MAX30102 ventana; MAX30205 ventana; 3x Ø6 electrodos M3

NOTAS:
1. Origen (0,0) = esquina inf-izq exterior
2. Esquinas verticales R12, paredes 2mm uniformes
3. Standoffs Z=2 a Z=4. Cilindros huecos para M2 self-tap
4. Ventanas y agujeros atraviesan TODO el piso (0 < Z < 2)
5. Seccion A-A en la pagina 2

BOTTOM CASE - VISTA EN PLANTA

Proyecto: SupaClock V2
Curso: IEE2913 Capstone PUC, Grupo 10
Escala: 1:1 (en unidades reales); Unidades: mm

## SECCION A-A (corte horizontal Y=39.5 = L/2)

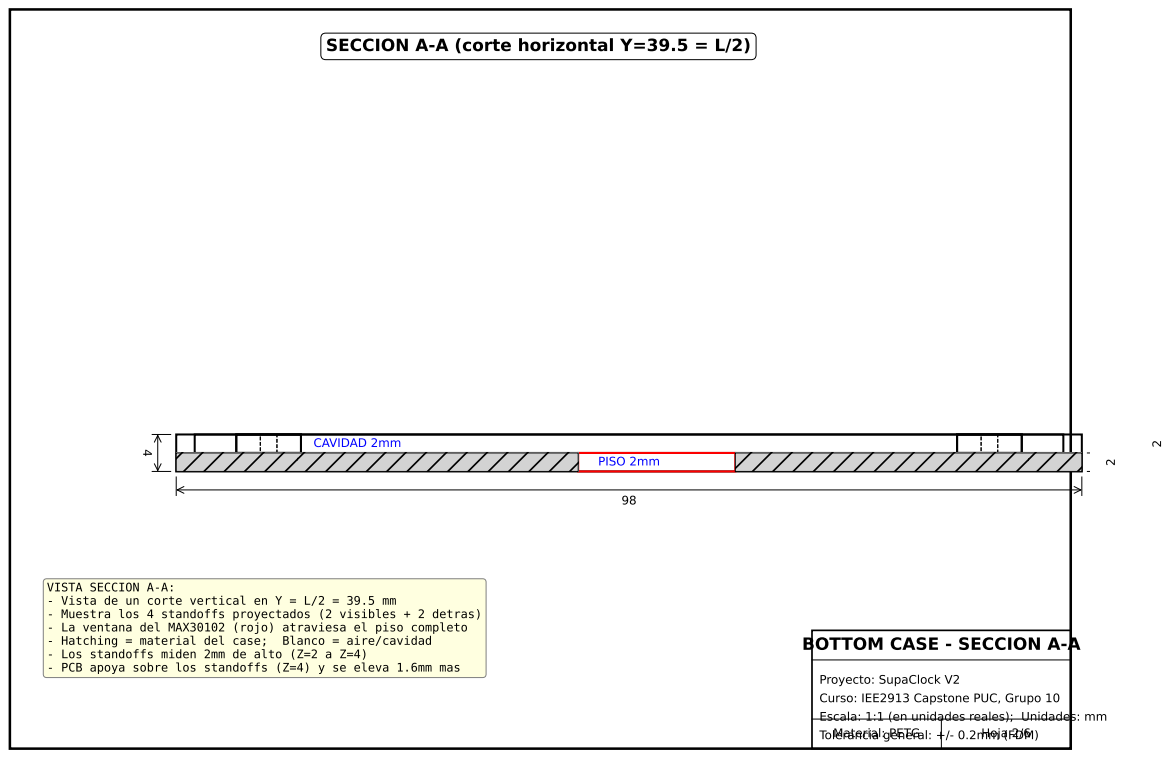
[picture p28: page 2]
Tolerancia general: +/- 0.2mm (FDM) Material: PETG; Hoja 2/6; - Hatching = material del case;; Blanco = aire/cavidad

CAVIDAD 2mm

PISO 2mm

VISTA SECCION A-A:
- Vista de un corte vertical en Y = L/2 = 39.5 mm
- Muestra los 4 standoffs proyectados (2 visibles + 2 detras)
- La ventana del MAX30102 (rojo) atraviesa el piso completo
- Los standoffs miden 2mm de alto (Z=2 a Z=4)
- PCB apoya sobre los standoffs (Z=4) y se eleva 1.6mm mas

BOTTOM CASE - SECCION A-A

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

## TOP CASE - PLANTA

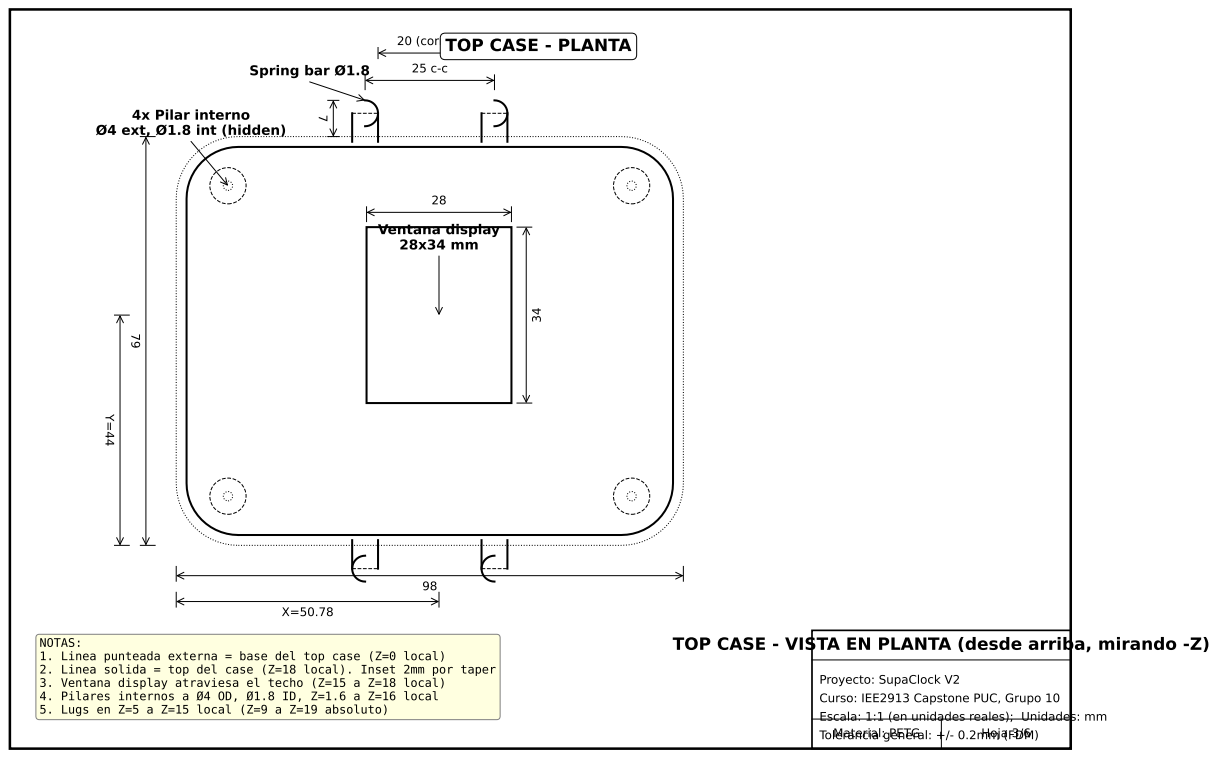
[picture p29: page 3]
Tolerancia general: +/- 0.2mm (FDM) Material: PETG; Hoja 3/6; Ventana display 28x34 mm; 20 (correa); Spring bar Ø1.8

4x Pilar interno
Ø4 ext, Ø1.8 int (hidden)

NOTAS:
1. Linea punteada externa = base del top case (Z=0 local)
2. Linea solida = top del case (Z=18 local). Inset 2mm por taper
3. Ventana display atraviesa el techo (Z=15 a Z=18 local)
4. Pilares internos a Ø4 OD, Ø1.8 ID, Z=1.6 a Z=16 local
5. Lugs en Z=5 a Z=15 local (Z=9 a Z=19 absoluto)

TOP CASE - VISTA EN PLANTA (desde arriba, mirando -Z)

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

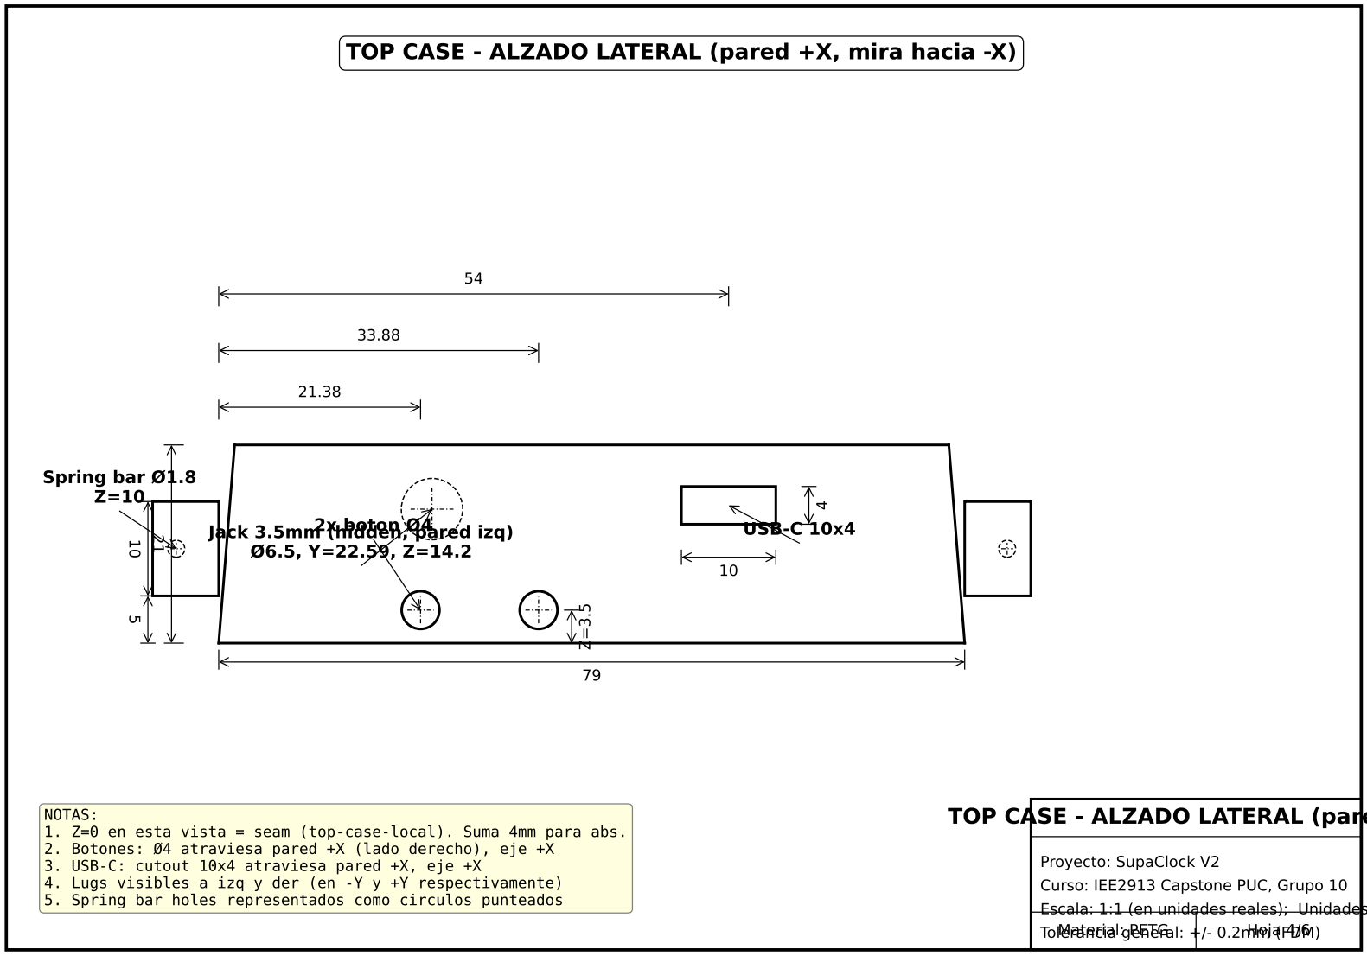
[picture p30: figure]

## TOP CASE - ALZADO FRONTAL (mira hacia +Y)

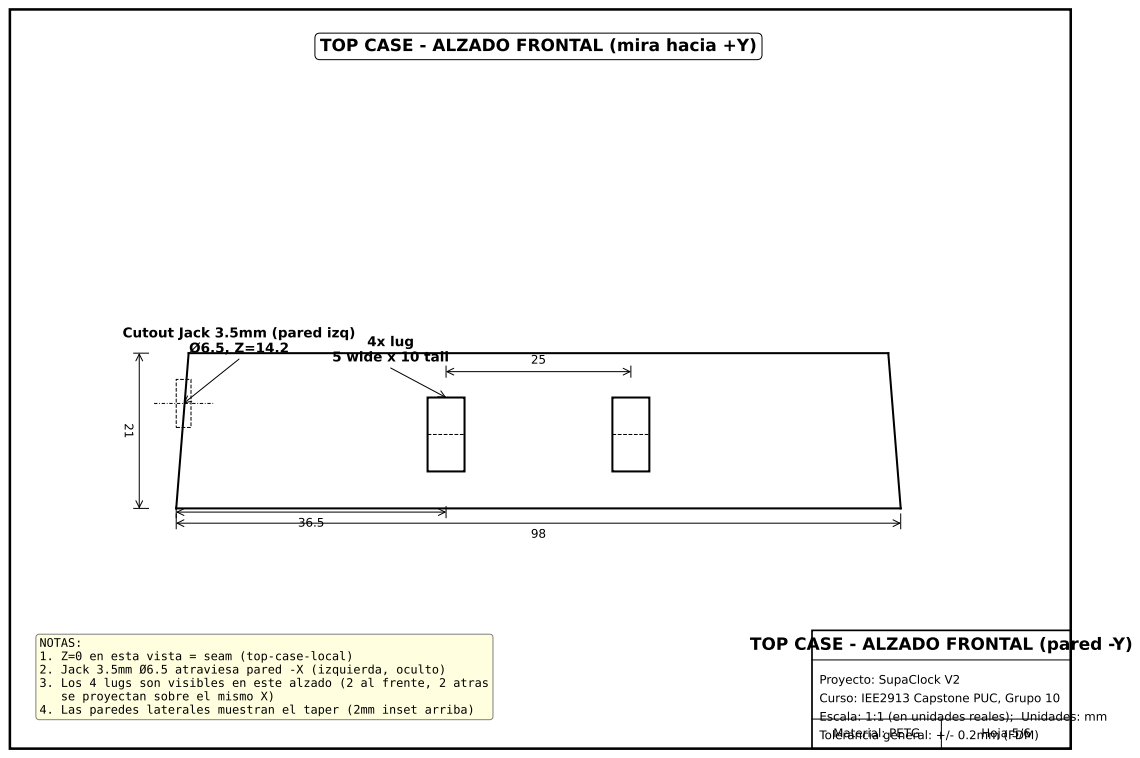
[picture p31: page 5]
Tolerancia general: +/- 0.2mm (FDM) Material: PETG; Hoja 5/6; 4x lug 5 wide x 10 tall

Cutout Jack 3.5mm (pared izq)

NOTAS:
1. Z=0 en esta vista = seam (top-case-local)
2. Jack 3.5mm Ø6.5 atraviesa pared -X (izquierda, oculto)
3. Los 4 lugs son visibles en este alzado (2 al frente, 2 atras
se proyectan sobre el mismo X)
4. Las paredes laterales muestran el taper (2mm inset arriba)

TOP CASE - ALZADO FRONTAL (pared -Y)

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

## DETALLE LUG (vista en planta, escala 7x) ¹⁰

Tolerancia general: +/- 0.2mm (FDM) Material: PETG; Hoja 6/6; Flange exterior; Stem; Retention lip conico

DETALLE BUTTON CAP
(seccion axial, 7x)

DETALLE LUG (alzado lateral, escala 7x)

Ø1.8 spring bar
(pasante a lo largo de X)

NOTAS GENERALES (todas las piezas):
1. Hatching = material solido en vistas de seccion
2. Lineas punteadas = aristas ocultas o bordes mas alla del corte
3. Cota maxima de R/Ø incluye 'Ø' para diametro, 'R' para radio
4. Origen de cada vista esta indicado por el centro de marca o por
la cota referida en (0,0) del feature
5. Tolerancia de impresion FDM tipica: +0.0 / -0.3 para huecos
roscados, +/-0.2 para dimensiones planas

DETALLES - LUG y BUTTON CAP

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

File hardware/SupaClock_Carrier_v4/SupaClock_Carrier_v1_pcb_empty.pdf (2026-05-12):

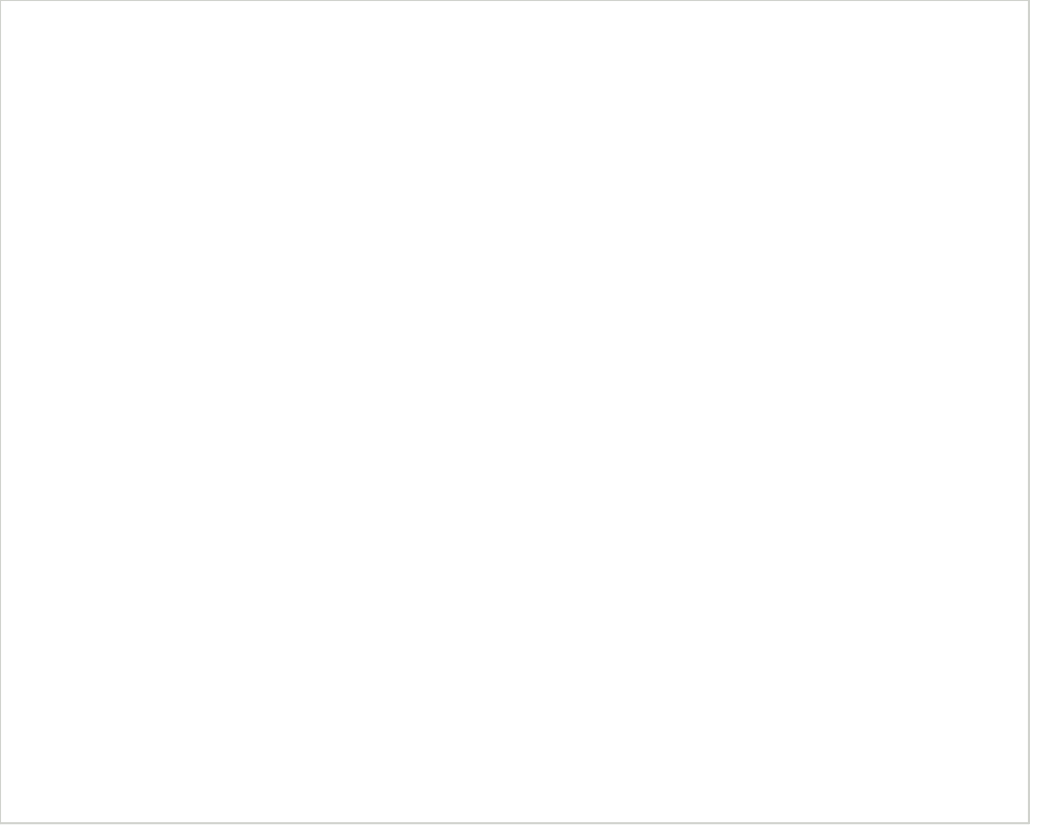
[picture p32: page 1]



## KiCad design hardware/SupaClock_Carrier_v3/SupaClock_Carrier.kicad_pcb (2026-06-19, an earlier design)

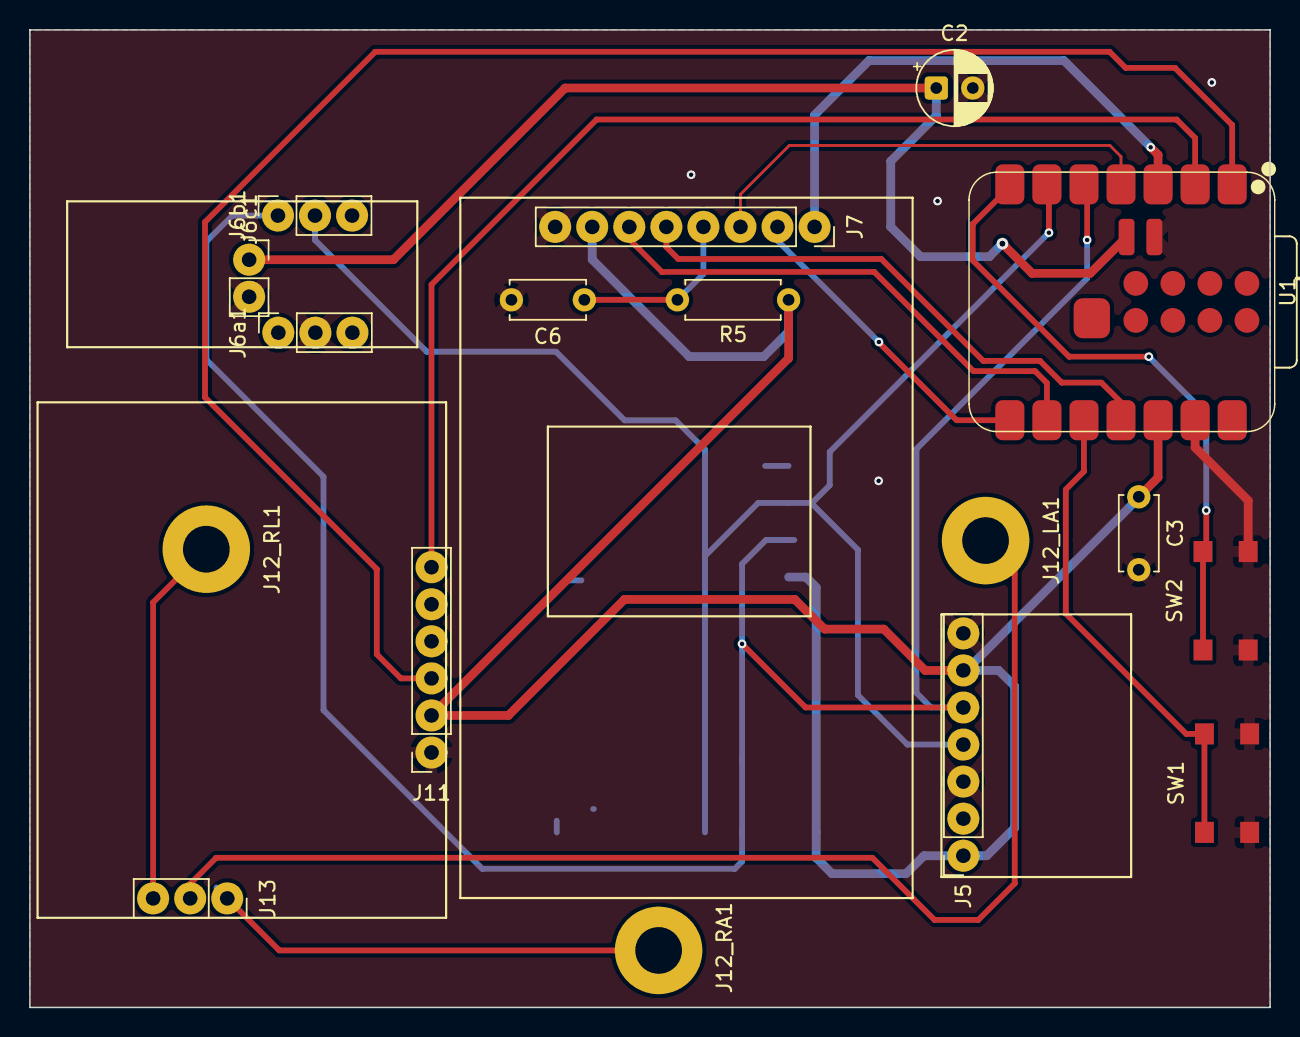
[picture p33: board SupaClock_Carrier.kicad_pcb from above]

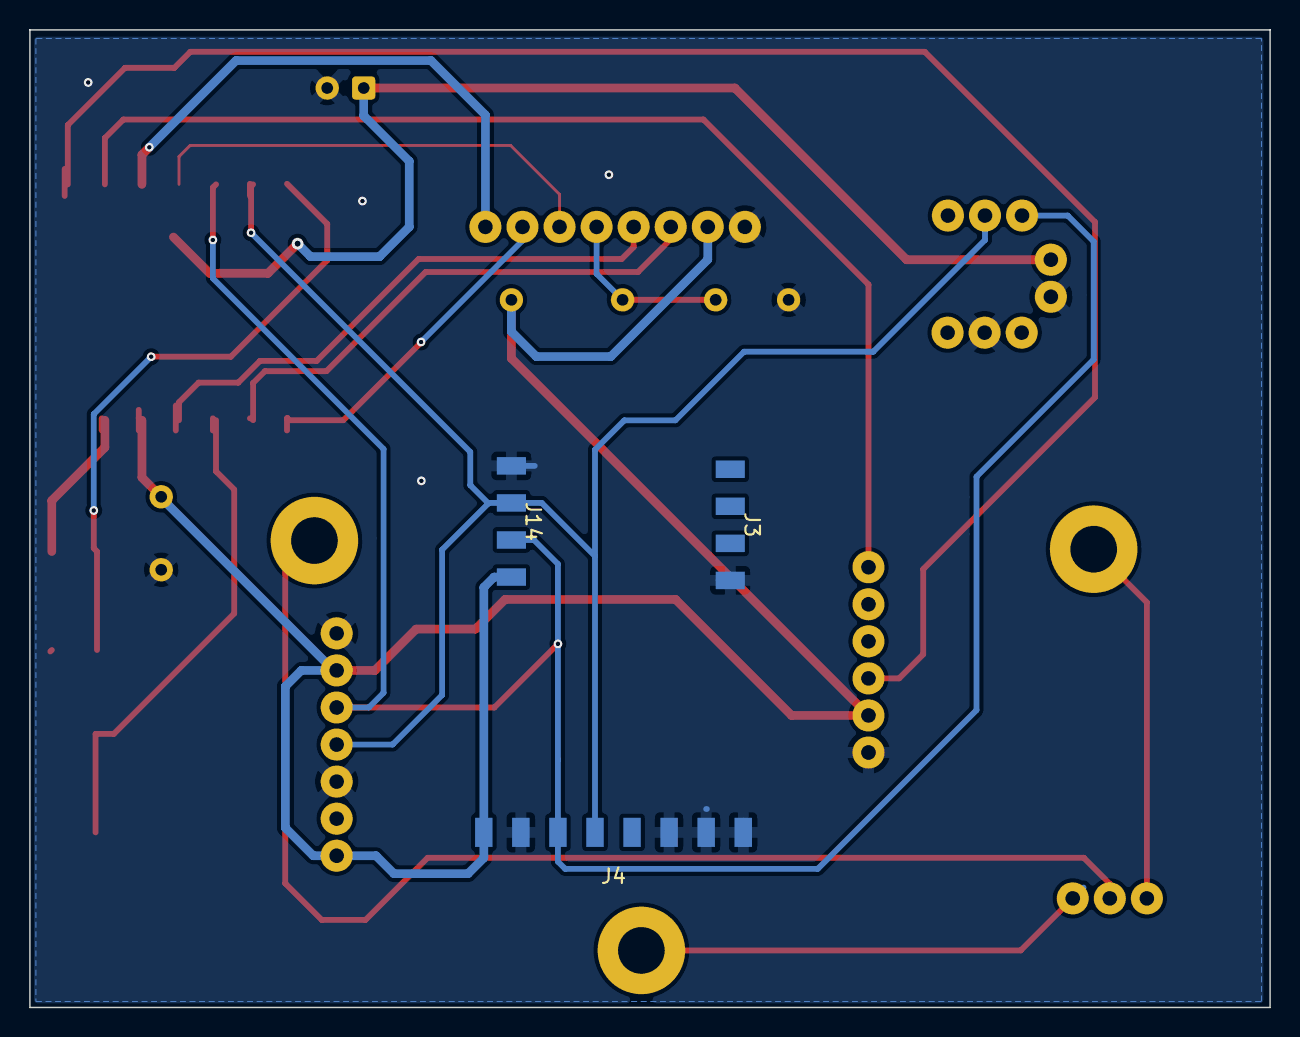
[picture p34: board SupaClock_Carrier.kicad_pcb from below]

Board: 2 copper layers, 85.0 x 67.0 mm, 20 parts (3 on the bottom side), 18 nets.

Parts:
C2: 10uF; CP_Radial_D5.0mm_P2.50mm
C3, C6: 100nF; C_Disc_D5.0mm_W2.5mm_P5.00mm
J3: MAX30102_top; MAX30102_Castellated_1x4
J4: MAX30205_8pad; MAX30205_8pad_Flush
J5: BMI160_7p; PinSocket_1x07_P2.54mm_Vertical
J6a1: MAX17048_L; PinSocket_1x03_P2.54mm_Vertical
J6b1: MAX17048_R; PinSocket_1x03_P2.54mm_Vertical
J6c1: MAX17048_BAT; PinSocket_1x02_P2.54mm_Vertical
J7: ST7789_1.69in; PinSocket_1x08_P2.54mm_Vertical
J11: AD8232_SparkFun; PinSocket_1x06_P2.54mm_Vertical
J12_LA1: ECG_LA_pad_M3; M3_Electrode_Pad
J12_RA1: ECG_RA_pad_M3; M3_Electrode_Pad
J12_RL1: ECG_RL_pad_M3; M3_Electrode_Pad
J13: AD8232_Pads_RA_LA_RL; PinSocket_1x03_P2.54mm_Vertical
J14: MAX30102_bot; MAX30102_Castellated_1x4
R5: 10k; R_Axial_DIN0207_L6.3mm_D2.5mm_P7.62mm_Horizontal
SW1: SELECT; SW_Tactile_Side_3.5x7.8mm
SW2: NEXT; SW_Tactile_Side_3.5x7.8mm
U1: XIAO-ESP32-S3; XIAO-ESP32-S3-SMD

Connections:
/+3V3: C3.1, J4.1, J5.1, J5.6, J7.7, J11.2, J14.1, R5.1, U1.12 (3V3)
/+BATT: C2.1, J6c1.1, U1.32 (BAT)
/BLK_PWM: J7.1, U1.3 (GPIO3_A2_D2)
/BTN_NEXT: SW2.1, U1.7 (GPIO43_D6_TX)
/BTN_SELECT: SW1.1, U1.10 (GPIO8_A9_D9_MISO)
/ECG_LA: J12_LA1.1 (Pin_1_1), J13.2
/ECG_OUT: J11.3, U1.1 (GPIO1_A0_D0)
/ECG_RA: J12_RA1.1 (Pin_1_1), J13.1
/ECG_RL: J12_RL1.1 (Pin_1_1), J13.3
/ECG_SDN: J11.6, U1.2 (GPIO2_A1_D1)
/GND: C2.2, C3.2, C6.2, J3.1 (Pin_1_1), J4.2, J4.6, J4.7, J4.8, J5.3, J5.7, J6a1.2 (Pin_2_2), J6c1.2, J7.8, J11.1, J14.4, SW1.2, SW2.2, U1.13 (GND), U1.33 (GND)
/I2C_SCL: J4.4, J5.4, J6b1.2, J14.3, U1.6 (GPIO6_A5_D5_SCL)
/I2C_SDA: J4.3, J5.5, J6b1.1, J14.2, U1.5 (GPIO5_A4_D4_SDA)
/SPI_CS: J7.2, U1.8 (GPIO44_D7_RX)
/SPI_DC: J7.3, U1.4 (GPIO4_A3_D3)
/SPI_MOSI: J7.5, U1.11 (GPIO9_A10_D10_MOSI)
/SPI_RES: C6.1, J7.4, R5.2
/SPI_SCK: J7.6, U1.9 (GPIO7_A8_D8_SCK)

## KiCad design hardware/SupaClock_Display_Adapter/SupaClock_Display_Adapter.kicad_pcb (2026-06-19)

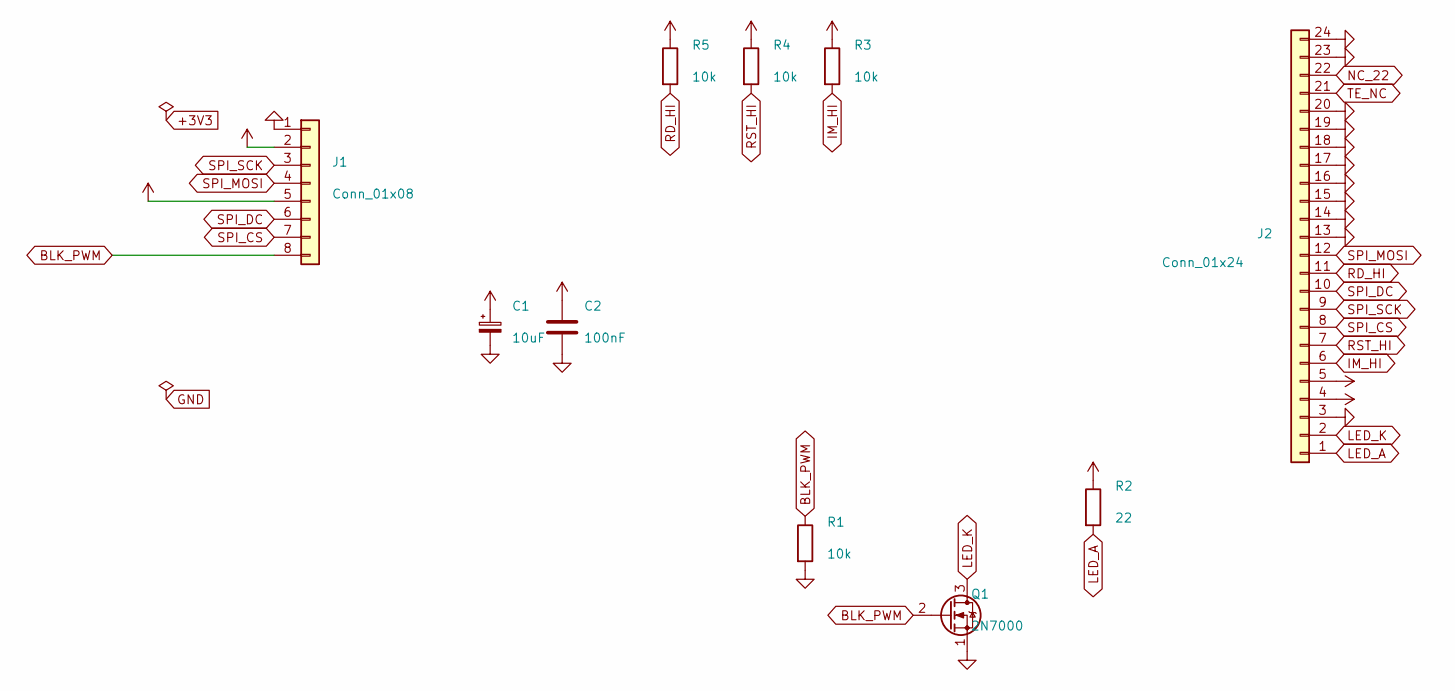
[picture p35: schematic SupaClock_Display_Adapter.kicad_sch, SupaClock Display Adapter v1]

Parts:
C1: 10uF; CP_Radial_D5.0mm_P2.50mm
C2: 100nF; C_Disc_D3.0mm_W1.6mm_P2.50mm
J1: Conn_01x08; PinHeader_1x08_P2.54mm_Vertical
J2: Conn_01x24; Hirose_FH12-24S-0.5SH_1x24-1MP_P0.50mm_Horizontal
Q1: 2N7000; TO-92_Inline
R1, R3, R4, R5: 10k; R_Axial_DIN0207_L6.3mm_D2.5mm_P10.16mm_Horizontal
R2: 22; R_Axial_DIN0207_L6.3mm_D2.5mm_P10.16mm_Horizontal

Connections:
+3V3: C1.1, C2.1, J1.2, J1.5, J2.4, J2.5, R2.1, R3.1, R4.1, R5.1
BLK_PWM: J1.8, Q1.2 (G), R1.1
GND: C1.2, C2.2, J1.1, J2.3, J2.13, J2.14, J2.15, J2.16, J2.17, J2.18, J2.19, J2.20, J2.23, J2.24, Q1.1 (S), R1.2
IM_HI: J2.6, R3.2
LED_A: J2.1, R2.2
LED_K: J2.2, Q1.3 (D)
NC_22: J2.22
RD_HI: J2.11, R5.2
RST_HI: J2.7, R4.2
SPI_CS: J1.7, J2.8
SPI_DC: J1.6, J2.10
SPI_MOSI: J1.4, J2.12
SPI_SCK: J1.3, J2.9
TE_NC: J2.21

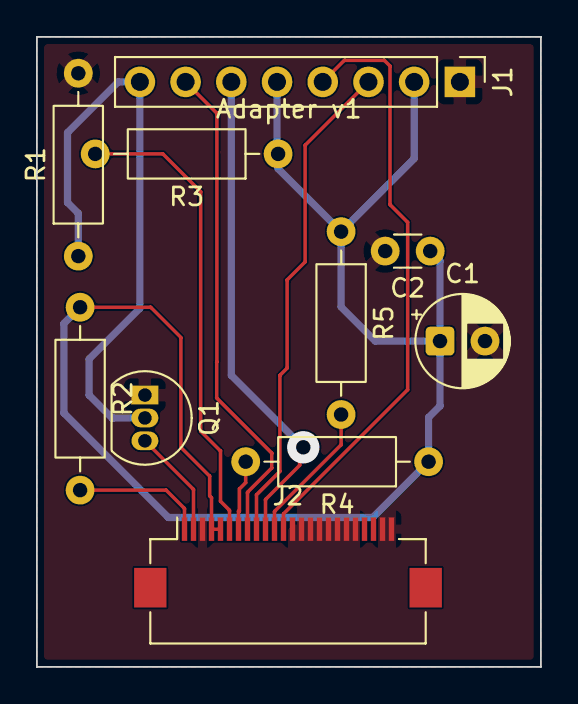
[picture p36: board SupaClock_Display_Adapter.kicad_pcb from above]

Board: 2 copper layers, 28.0 x 35.0 mm, 10 parts (0 on the bottom side), 12 nets.

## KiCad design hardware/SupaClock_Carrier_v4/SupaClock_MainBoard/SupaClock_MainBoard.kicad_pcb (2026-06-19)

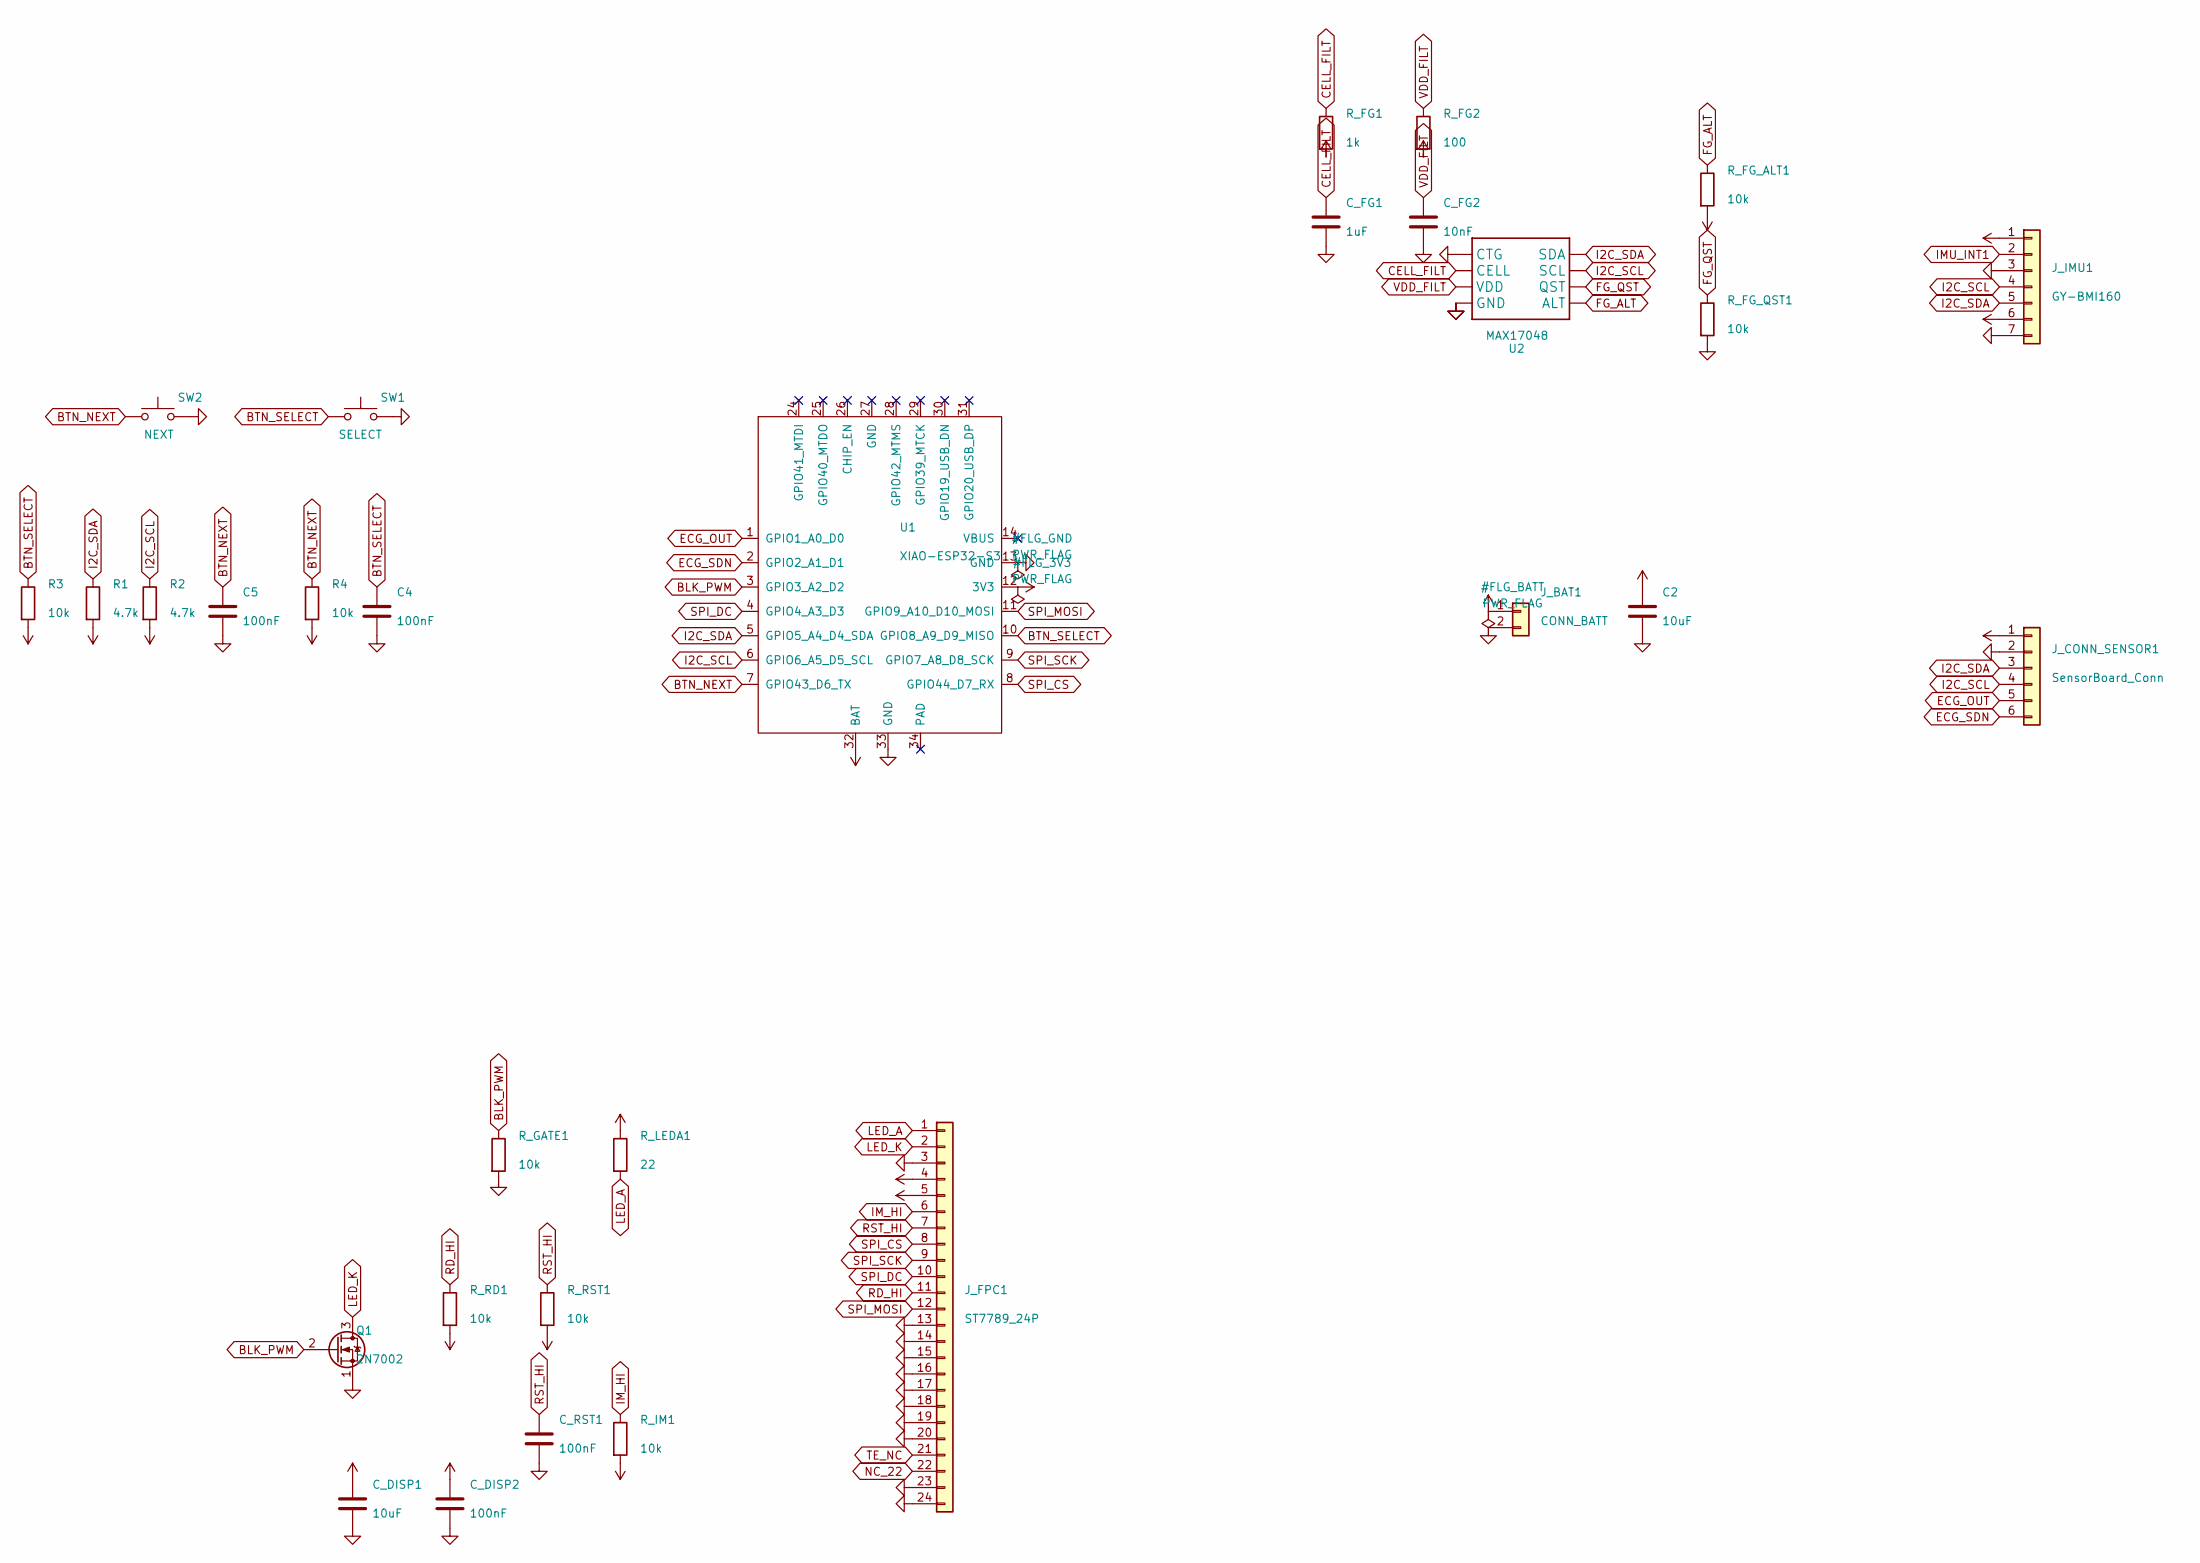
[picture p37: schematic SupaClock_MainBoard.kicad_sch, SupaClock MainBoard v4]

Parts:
C2: 10uF; C_0805_2012Metric_Pad1.18x1.45mm_HandSolder
C4, C5: 100nF; C_0805_2012Metric_Pad1.18x1.45mm_HandSolder
C_DISP1: 10uF; C_0805_2012Metric_Pad1.18x1.45mm_HandSolder
C_DISP2: 100nF; C_0805_2012Metric_Pad1.18x1.45mm_HandSolder
C_FG1: 1uF; C_0805_2012Metric_Pad1.18x1.45mm_HandSolder
C_FG2: 10nF; C_0805_2012Metric_Pad1.18x1.45mm_HandSolder
C_RST1: 100nF; C_0805_2012Metric_Pad1.18x1.45mm_HandSolder
J_BAT1: CONN_BATT; JST_PH_B2B-PH-K_1x02_P2.00mm_Vertical
J_CONN_SENSOR1: SensorBoard_Conn; JST_PH_B6B-PH-K_1x06_P2.00mm_Vertical
J_FPC1: ST7789_24P; Hirose_FH12-24S-0.5SH_1x24-1MP_P0.50mm_Horizontal
J_IMU1: GY-BMI160; PinHeader_1x07_P2.54mm_Vertical
Q1: 2N7002; SOT-23_Handsoldering
R1, R2: 4.7k; R_0805_2012Metric_Pad1.20x1.40mm_HandSolder
R3, R4: 10k; R_0805_2012Metric_Pad1.20x1.40mm_HandSolder
R_FG1: 1k; R_0805_2012Metric_Pad1.20x1.40mm_HandSolder
R_FG2: 100; R_0805_2012Metric_Pad1.20x1.40mm_HandSolder
R_FG_ALT1: 10k; R_0805_2012Metric_Pad1.20x1.40mm_HandSolder
R_FG_QST1: 10k; R_0805_2012Metric_Pad1.20x1.40mm_HandSolder
R_GATE1: 10k; R_0805_2012Metric_Pad1.20x1.40mm_HandSolder
R_IM1: 10k; R_0805_2012Metric_Pad1.20x1.40mm_HandSolder
R_LEDA1: 22; R_0805_2012Metric_Pad1.20x1.40mm_HandSolder
R_RD1: 10k; R_0805_2012Metric_Pad1.20x1.40mm_HandSolder
R_RST1: 10k; R_0805_2012Metric_Pad1.20x1.40mm_HandSolder
SW1: SELECT; SW_Tactile_Side_3.5x7.8mm
SW2: NEXT; SW_Tactile_Side_3.5x7.8mm
U1: XIAO-ESP32-S3; XIAO-ESP32-S3-SMD
U2: MAX17048; MAX17048_WDFN8_HandSolder

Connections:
+3V3: C_DISP1.1, C_DISP2.1, J_CONN_SENSOR1.1, J_FPC1.4, J_FPC1.5, J_IMU1.1, J_IMU1.6, R1.2, R2.2, R3.2, R4.2, R_FG_ALT1.2, R_IM1.2, R_LEDA1.1, R_RD1.2, R_RST1.2, U1.12 (3V3)
+BATT: C2.1, J_BAT1.1, R_FG1.2, R_FG2.2, U1.32 (BAT)
BLK_PWM: Q1.2 (G), R_GATE1.1, U1.3 (GPIO3_A2_D2)
BTN_NEXT: C5.1, R4.1, SW2.1, U1.7 (GPIO43_D6_TX)
BTN_SELECT: C4.1, R3.1, SW1.1, U1.10 (GPIO8_A9_D9_MISO)
CELL_FILT: C_FG1.1, R_FG1.1, U2.2 (CELL)
ECG_OUT: J_CONN_SENSOR1.5, U1.1 (GPIO1_A0_D0)
ECG_SDN: J_CONN_SENSOR1.6, U1.2 (GPIO2_A1_D1)
FG_ALT: R_FG_ALT1.1, U2.5 (ALT)
FG_QST: R_FG_QST1.1, U2.6 (QST)
GND: C2.2, C4.2, C5.2, C_DISP1.2, C_DISP2.2, C_FG1.2, C_FG2.2, C_RST1.2, J_BAT1.2, J_CONN_SENSOR1.2, J_FPC1.3, J_FPC1.13, J_FPC1.14, J_FPC1.15, J_FPC1.16, J_FPC1.17, J_FPC1.18, J_FPC1.19, J_FPC1.20, J_FPC1.23, J_FPC1.24, J_IMU1.3, J_IMU1.7, Q1.1 (S), R_FG_QST1.2, R_GATE1.2, SW1.2, SW2.2, U1.13 (GND), U1.33 (GND), U2.1 (CTG), U2.4 (GND), U2.EP (GND)
I2C_SCL: J_CONN_SENSOR1.4, J_IMU1.4, R2.1, U1.6 (GPIO6_A5_D5_SCL), U2.7 (SCL)
I2C_SDA: J_CONN_SENSOR1.3, J_IMU1.5, R1.1, U1.5 (GPIO5_A4_D4_SDA), U2.8 (SDA)
IMU_INT1: J_IMU1.2
IM_HI: J_FPC1.6, R_IM1.1
LED_A: J_FPC1.1, R_LEDA1.2
LED_K: J_FPC1.2, Q1.3 (D)
NC_22: J_FPC1.22
RD_HI: J_FPC1.11, R_RD1.1
RST_HI: C_RST1.1, J_FPC1.7, R_RST1.1
SPI_CS: J_FPC1.8, U1.8 (GPIO44_D7_RX)
SPI_DC: J_FPC1.10, U1.4 (GPIO4_A3_D3)
SPI_MOSI: J_FPC1.12, U1.11 (GPIO9_A10_D10_MOSI)
SPI_SCK: J_FPC1.9, U1.9 (GPIO7_A8_D8_SCK)
TE_NC: J_FPC1.21
VDD_FILT: C_FG2.1, R_FG2.1, U2.3 (VDD)

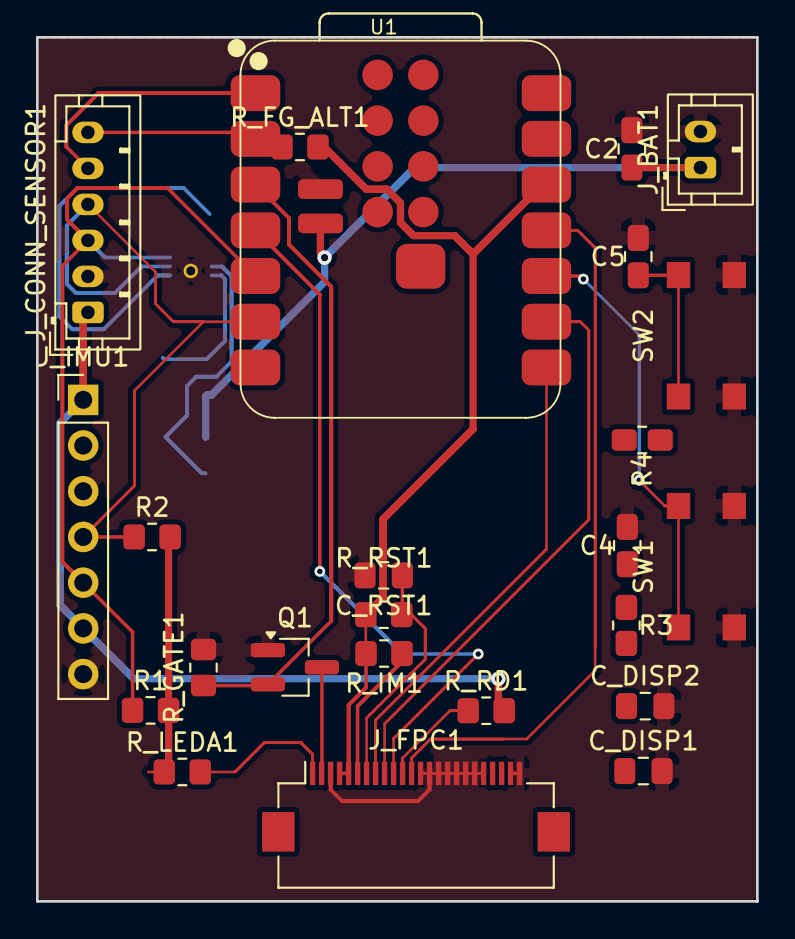
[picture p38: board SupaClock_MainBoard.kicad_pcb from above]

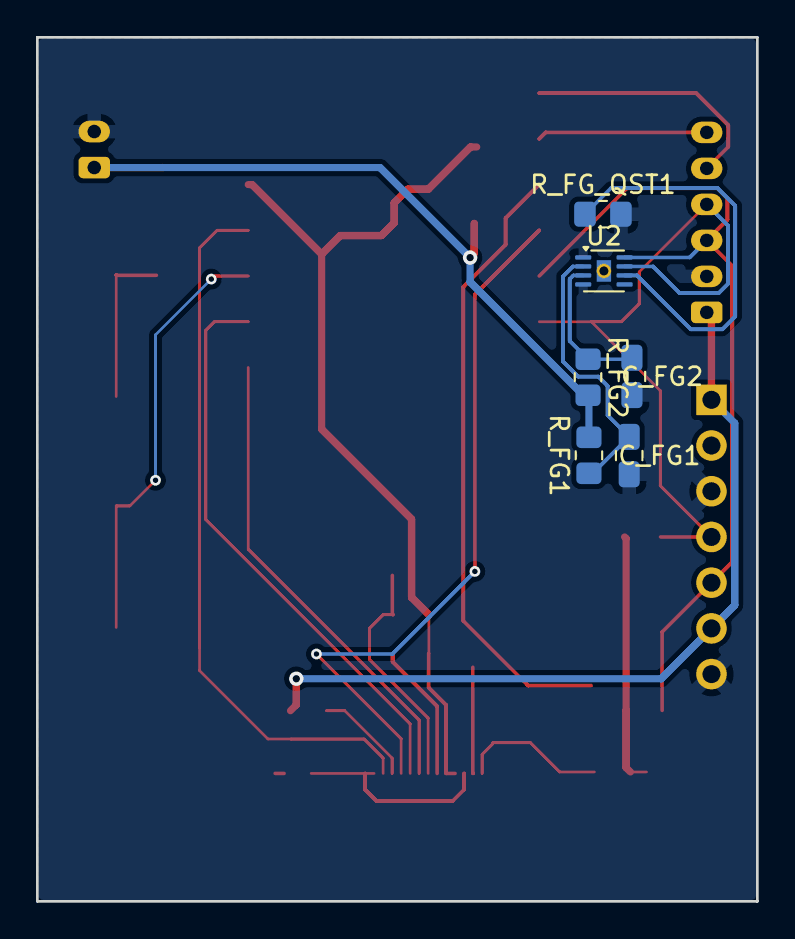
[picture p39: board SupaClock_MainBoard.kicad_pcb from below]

Board: 2 copper layers, 40.0 x 48.0 mm, 30 parts (6 on the bottom side), 23 nets.

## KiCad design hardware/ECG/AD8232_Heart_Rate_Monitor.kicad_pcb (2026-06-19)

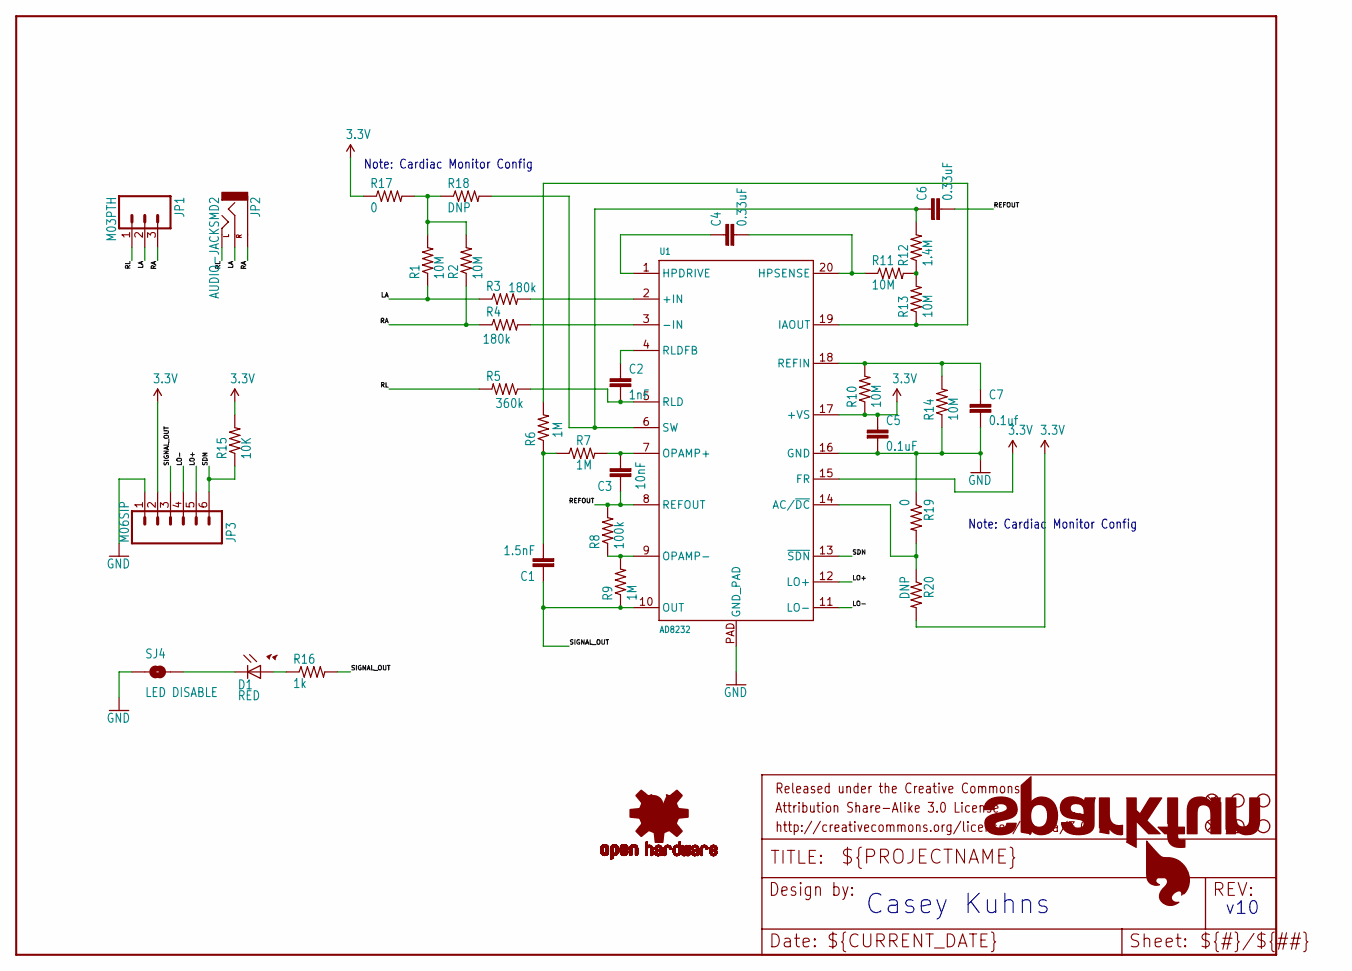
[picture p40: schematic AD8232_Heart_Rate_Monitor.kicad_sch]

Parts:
C1: 1.5nF; 0603-CAP
C2: 1nF; 0603-CAP
C3: 10nF; 0603-CAP
C4, C6: 0.33uF; 0805
C5: 0.1uF; 0603-CAP
C7: 0.1uf; 0603-CAP
D1: RED; LED-0603
FID1, FID2: FIDUCIAL1X2; FIDUCIAL-1X2
FRAME1: FRAME-LETTER; CREATIVE_COMMONS
JP1: M03PTH; 1X03
JP2: AUDIO-JACKSMD2; AUDIO-JACK-3.5MM-SMD
JP3: M06SIP; 1X06
LOGO1: OSHW-LOGOS; OSHW-LOGO-S
LOGO2: SFE_LOGO_NAME_FLAME.1_INCH; SFE_LOGO_NAME_FLAME_.1
R1, R2, R10, R11, R13, R14: 10M; 0603-RES
R3, R4: 180k; 0603-RES
R5: 360k; 0603-RES
R6, R7, R9: 1M; 0603-RES
R8: 100k; 0603-RES
R12: 1.4M; 0603-RES
R15: 10K; 0603-RES
R16: 1k; 0603-RES
R17, R19: 0; 0603
R18, R20: DNP; 0603
SJ4: LED DISABLE; SJ_2S-TRACE
STANDOFF1, STANDOFF2, STANDOFF3, STANDOFF4: STAND-OFF
U1: AD8232; LFCSP_20

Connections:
3.3V: C5.1, JP3.2, R10.1, R15.2, R17.1, R20.2, U1.15 (FR), U1.17 (+VS)
GND: C5.2, C7.2, JP3.1, R14.1, R19.1, SJ4.1, U1.16 (GND), U1.PAD (GND_PAD)
LA: JP1.2, JP2.RING (RIGHT), R1.1, R3.1
LO+: JP3.5, U1.12 (LO+)
LO-: JP3.4, U1.11 (LO-)
unnamed: R3.2, U1.2 (+IN)
unnamed: R4.2, U1.3 (-IN)
unnamed: C3.2, R7.2, U1.7 (OPAMP+)
unnamed: C4.2, R11.1, U1.20 (HPSENSE)
unnamed: C7.1, R10.2, R14.2, U1.18 (REFIN)
unnamed: D1.A, R16.1
unnamed: R8.1, R9.2, U1.9 (OPAMP-)
unnamed: R6.2, R13.1, U1.19 (IAOUT)
unnamed: C1.2, R6.1, R7.1
unnamed: D1.C, SJ4.2
unnamed: R19.2, R20.1, U1.14 (AC/~DC)
unnamed: C4.1, U1.1 (HPDRIVE)
unnamed: R11.2, R12.1, R13.2
unnamed: C6.1, R12.2, R18.2, U1.6 (SW)
unnamed: C2.1, U1.4 (RLDFB)
unnamed: C2.2, R5.1, U1.5 (RLD)
unnamed: R1.2, R2.2, R17.2, R18.1
RA: JP1.3, JP2.SLEEVE, R2.1, R4.1
REFOUT: C3.1, C6.2, R8.2, U1.8 (REFOUT)
RL: JP1.1, JP2.TIP (LEFT), R5.2
SDN: JP3.6, R15.1, U1.13 (~SDN)
SIGNAL_OUT: C1.1, JP3.3, R9.1, R16.2, U1.10 (OUT)

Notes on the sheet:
Note: Cardiac Monitor Config
v10
Casey Kuhns

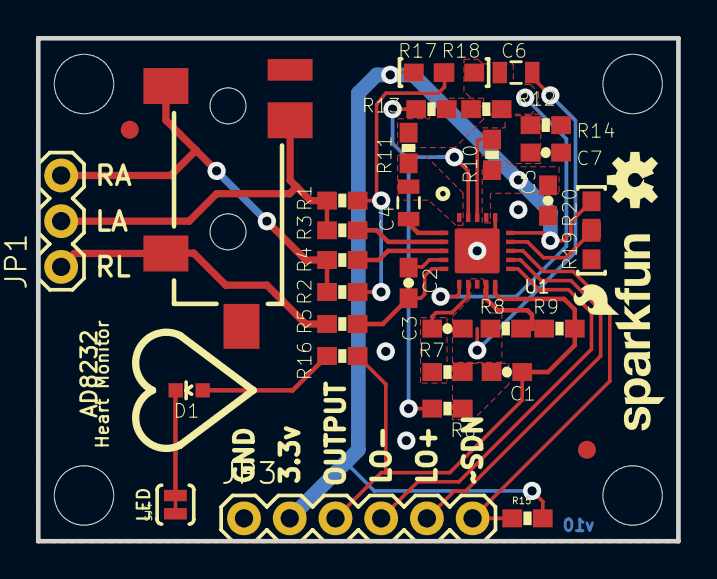
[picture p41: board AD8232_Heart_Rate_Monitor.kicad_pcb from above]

Board: 2 copper layers, 35.6 x 27.9 mm, 42 parts (0 on the bottom side), 27 nets.

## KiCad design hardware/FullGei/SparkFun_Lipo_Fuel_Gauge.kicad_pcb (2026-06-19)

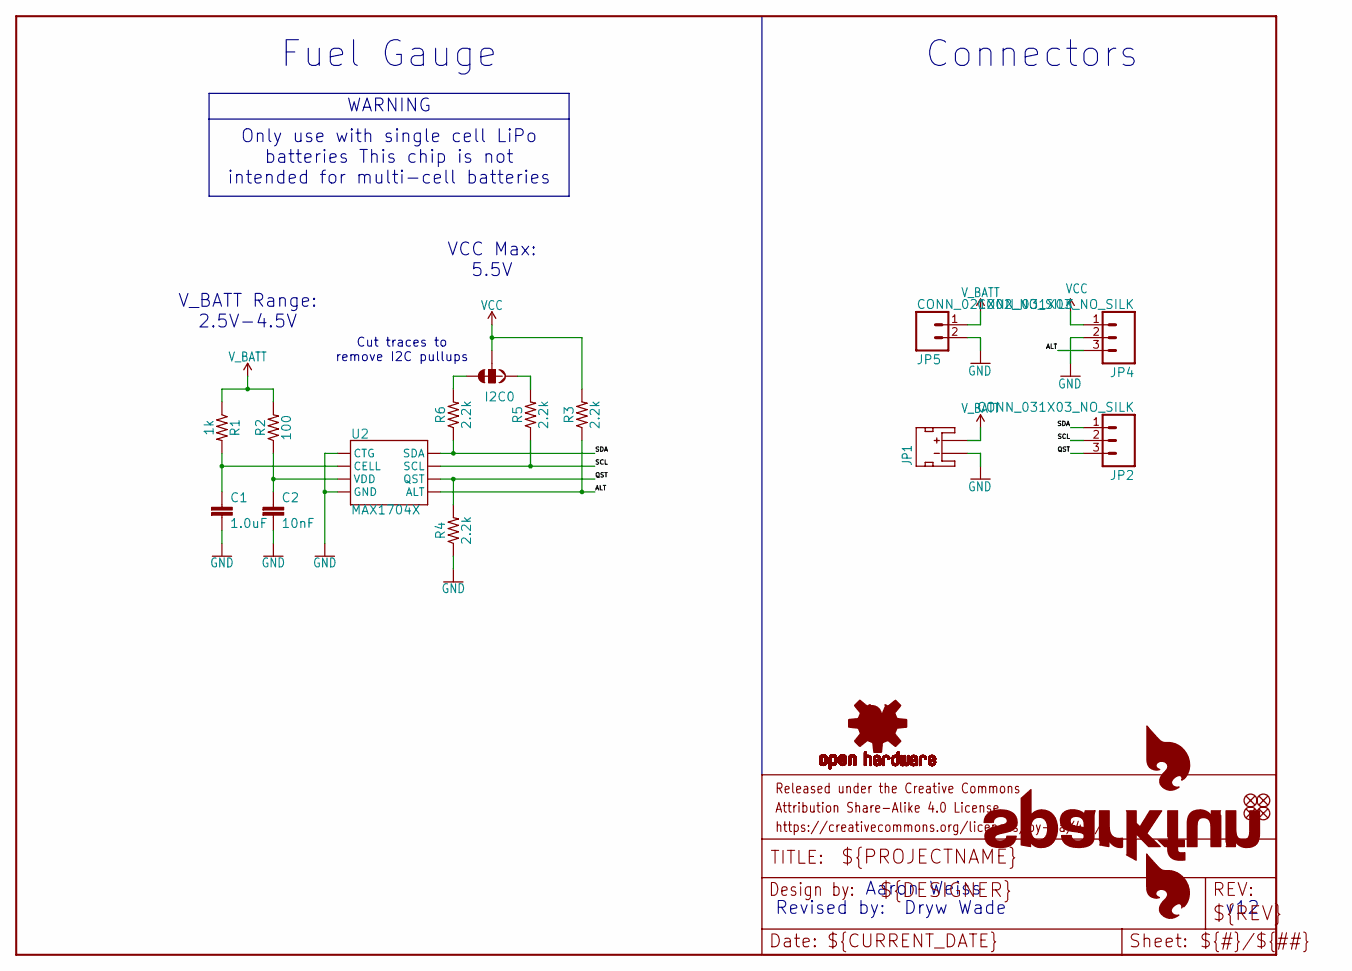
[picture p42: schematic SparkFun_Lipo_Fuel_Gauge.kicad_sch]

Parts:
C1: 1.0uF; 0402-TIGHT
C2: 10nF; 0402-TIGHT
FRAME1: FRAME-LETTER; CREATIVE_COMMONS
I2C0: JUMPER-SMT_3_2-NC_TRACE_SILK; SMT-JUMPER_3_2-NC_TRACE_SILK
JP1: input; JST-2-SMD
JP2, JP4: CONN_031X03_NO_SILK; 1X03_NO_SILK
JP3: SFE_LOGO_FLAME.1_INCH; SFE_LOGO_FLAME_.1
JP5: CONN_021X02_NO_SILK; 1X02_NO_SILK
JP6, JP7, JP8, JP9: FIDUCIALUFIDUCIAL; FIDUCIAL-MICRO
LOGO1: SFE_LOGO_NAME_FLAMEBLANK; BLANK
R1: 1k; 0402-TIGHT
R2: 100; 0402-TIGHT
R3, R4, R5, R6: 2.2k; 0402-TIGHT
U2: MAX1704X; TDFN-8
U$1: OSHW-LOGOS; OSHW-LOGO-S

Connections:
ALT: JP4.3, R3.1, U2.5 (ALT)
GND: C1.2, C2.2, JP1.1 (-), JP4.2, JP5.2, R4.1, U2.1 (CTG), U2.4 (GND), U2.EP (GND)
unnamed: I2C0.3, R6.2
unnamed: C1.1, R1.2, U2.2 (CELL)
unnamed: I2C0.1, R5.2
QST: JP2.3, R4.2, U2.6 (QST)
SCL: JP2.2, R5.1, U2.7 (SCL)
SDA: JP2.1, R6.1, U2.8 (SDA)
VCC: I2C0.2, JP4.1, R3.2
VDD: C2.1, R2.1, U2.3 (VDD)
V_BATT: JP1.2 (+), JP5.1, R1.1, R2.2

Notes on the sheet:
Aaron Weiss
Cut traces to remove I2C pullups
VCC Max: 5.5V
Dryw Wade
V_BATT Range: 2.5V-4.5V
Revised by:
Only use with single cell LiPo batteries~{} This chip is not intended for multi-cell batteries~{}
Connectors
Fuel Gauge
WARNING
v12

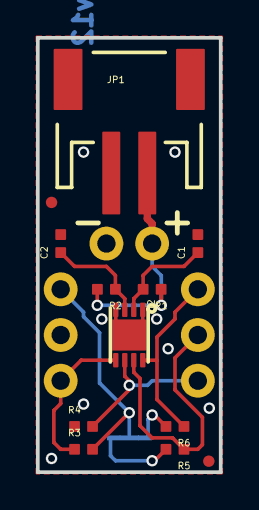
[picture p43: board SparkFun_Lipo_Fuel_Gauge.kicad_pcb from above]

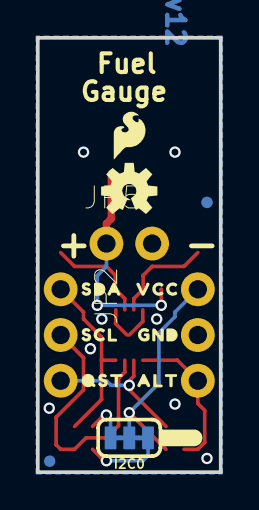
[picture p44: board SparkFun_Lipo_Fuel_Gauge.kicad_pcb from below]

Board: 2 copper layers, 10.2 x 24.1 mm, 29 parts (15 on the bottom side), 11 nets.

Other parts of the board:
U$2: SDA0
U$3: SCL0
U$4: QST0
U$5: VCC0
U$6: GND0
U$7: ALT0
U$8: #I2C#0

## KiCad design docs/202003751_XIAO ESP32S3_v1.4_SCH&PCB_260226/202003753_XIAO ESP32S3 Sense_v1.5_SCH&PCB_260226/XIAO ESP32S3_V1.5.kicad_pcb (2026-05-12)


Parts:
U6: LOGO_CC_BY-SA_4.0

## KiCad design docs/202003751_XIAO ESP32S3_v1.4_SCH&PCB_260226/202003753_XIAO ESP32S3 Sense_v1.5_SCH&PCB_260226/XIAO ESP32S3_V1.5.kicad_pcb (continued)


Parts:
ANT1: U.FL-R-SMT-1; U-FL3P-SMD-2.6X2.6X1.0MM
BAT0: VBAT; TP-80X40MIL
C1, C2, C17, C20: DNP; C0201; not fitted
C3, C9, C13, C16: 2.2uF; C0201
C4, C5, C6: 4.7uF; C0201
C7, C8, C28: 10pF; C0201
C10, C21, C25, C26: 1uF; C0201
C11, C14, C15, C19, C22, C23, C29, C30: 100nF; C0201
C12: 10nF; C0201
C18: 1pF; C0201
CHG0: RED; LED-0402
D2: LMBR4010BST5G; DFN1006-2L
D3: Yellow; LED-0402
GND0: GND; TP-80X40MIL
J3: DF40C-30DP-0.4V(51); BTB30-0.4-7.52X2.97X1.14
K1, K2: SKTAAAE010/311021459; SW4-SMD-2.8-2.6X1.6X0.53MM
L1: 2nH; L0201
L2: 3.3nH; L0201
L3: DNP; L0201; not fitted
L4: 470nH; L0603
L5: 24nH; L0201
Q1: LP0404N3T5G; PMOS_1.0_0.6_0.35MM
R1, R2: 5.1K; R0201
R3, R4: 22R; R0201
R6: 499R; R0201
R7, R8, R11: 10K; R0201
R9: 100K; C0201
R10: 220K; R0201
R13: 249K; R0201
R15: 1.5K; R0201
TP1, TP2, TP3, TP4, TP5, TP6, TP7, TP8: TEST-POINT'4545'; TP-D45MIL
U1: ESP32-S3R8; QFN56G-0.4-7X7MM
U3: SGM6029CYG/TR; BGA6-0.35-0.745X10.95X0.4MM
U4: SGM40567-4.2XG/TR; WLCSP-0.4-0.92X1.16X0.4MM
U5: GD25Q64ENIGR; USON8-0.8-4X3MM
U8: LOGO_CC_BY-SA_4.0
U9: XIAO-Add-On; XIAO-14P-Add-On
USB0: UBF31-0171; USB2.0-TYPE-C
X1: 40MHz/306011364; X4-SMD-1.6X1.2X0.35MM

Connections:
/03 XIAO ESP32-S3-Sense/D0/A0: U1.6 (GPIO1), U9.1 (D0)
/03 XIAO ESP32-S3-Sense/D1/A1: U1.7 (GPIO2), U9.2 (D1)
/03 XIAO ESP32-S3-Sense/D2/A2: J3.2, U1.8 (GPIO3), U9.3 (D2)
/03 XIAO ESP32-S3-Sense/D3/A3: U1.9 (GPIO4), U9.4 (D3)
/03 XIAO ESP32-S3-Sense/D4/I2C_SDA: U1.10 (GPIO5), U9.5 (D4)
/03 XIAO ESP32-S3-Sense/D5/I2C_SCL: U1.11 (GPIO6), U9.6 (D5)
/03 XIAO ESP32-S3-Sense/D6/TX: R6.2, U9.7 (D6)
/03 XIAO ESP32-S3-Sense/D7/RX: U1.50 (U0RXD), U9.8 (D7)
/03 XIAO ESP32-S3-Sense/D8/A8/SCK: J3.3, U1.12 (GPIO7), U9.9 (D8)
/03 XIAO ESP32-S3-Sense/D9/A9/MISO: J3.4, U1.13 (GPIO8), U9.10 (D9)
/03 XIAO ESP32-S3-Sense/D10/A10/MOSI: J3.5, U1.14 (GPIO9), U9.11 (D10)
/03 XIAO ESP32-S3-Sense/EN: C21.2, K1.1 (A0), K1.3 (A1), R8.1, TP6.T, U1.4 (CHIP_PU)
/03 XIAO ESP32-S3-Sense/ESP_USB_D+: C1.2, R4.2, TP8.T, U1.26 (GPIO20)
/03 XIAO ESP32-S3-Sense/ESP_USB_D-: C2.2, R3.2, TP7.T, U1.25 (GPIO19)
/03 XIAO ESP32-S3-Sense/GPIO0: C28.2, K2.1 (A0), K2.3 (A1), R7.1, U1.5 (GPIO0)
/03 XIAO ESP32-S3-Sense/IO10/XMCLK: J3.6, U1.15 (GPIO10)
/03 XIAO ESP32-S3-Sense/IO11/DVP_Y8: J3.7, U1.16 (GPIO11)
/03 XIAO ESP32-S3-Sense/IO12/DVP_Y7: J3.8, U1.17 (GPIO12)
/03 XIAO ESP32-S3-Sense/IO13/DVP_PCLK: J3.9, U1.18 (GPIO13)
/03 XIAO ESP32-S3-Sense/IO14/DVP_Y6: J3.10, U1.19 (GPIO14)
/03 XIAO ESP32-S3-Sense/IO15/DVP_Y2: J3.11, U1.21 (XTAL_32K_P)
/03 XIAO ESP32-S3-Sense/IO16/DVP_Y5: J3.12, U1.22 (XTAL_32K_N)
/03 XIAO ESP32-S3-Sense/IO17/DVP_Y3: J3.13, U1.23 (GPIO17)
/03 XIAO ESP32-S3-Sense/IO18/DVP_Y4: J3.14, U1.24 (GPIO18)
/03 XIAO ESP32-S3-Sense/IO21/USER_LED: D3.-, J3.16, U1.27 (GPIO21)
/03 XIAO ESP32-S3-Sense/IO38/DVP_VSYNC: J3.23, U1.43 (GPIO38)
/03 XIAO ESP32-S3-Sense/IO47/DVP_HREF: J3.22, U1.37 (SPICLK_P)
/03 XIAO ESP32-S3-Sense/IO48/DVP_Y9: J3.21, U1.36 (SPICLK_N)
/03 XIAO ESP32-S3-Sense/MTCK/IO39/CAM_SCL: J3.24, TP5.T, U1.44 (MTCK)
/03 XIAO ESP32-S3-Sense/MTDI/IO41/PDM_DATA: J3.26, TP3.T, U1.47 (MTDI)
/03 XIAO ESP32-S3-Sense/MTDO/IO40/CAM_SDA: J3.25, TP4.T, U1.45 (MTDO)
/03 XIAO ESP32-S3-Sense/MTMS/IO42/PDM_CLK: J3.27, TP2.T, U1.48 (MTMS)
/03 XIAO ESP32-S3-Sense/SPICLK: U1.33 (SPICLK), U5.6 (CLK)
/03 XIAO ESP32-S3-Sense/SPICS0: U1.32 (SPICS0), U5.1 (/CS)
/03 XIAO ESP32-S3-Sense/SPID: U1.35 (SPID), U5.5 (DIO)
/03 XIAO ESP32-S3-Sense/SPIHD: U1.30 (SPIHD), U5.7 (/HOLD)
/03 XIAO ESP32-S3-Sense/SPIQ: U1.34 (SPIQ), U5.2 (DO)
/03 XIAO ESP32-S3-Sense/SPIWP: U1.31 (SPIWP), U5.3 (/WP)
/03 XIAO ESP32-S3-Sense/USB_D+: R4.1, USB0.A6 (A6/DP1), USB0.B6 (B6/DP2)
/03 XIAO ESP32-S3-Sense/USB_D-: R3.1, USB0.A7 (A7/DN1), USB0.B7 (B7/DN2)
/03 XIAO ESP32-S3-Sense/VBAT: BAT0.1 (T), C26.1, Q1.1 (D), U4.A1 (BAT)
/03 XIAO ESP32-S3-Sense/VBUS: C10.1, C25.1, D2.+, Q1.2 (G), R9.2, R11.1, U4.A2 (VIN), U9.14 (VBUS), USB0.A4_B9 (A4/B9/VBUS), USB0.B4_A9 (B4/A9/VBUS)
/03 XIAO ESP32-S3-Sense/VCC_3V3: C5.2, C6.2, C9.2, C11.2, C12.2, C13.2, C14.2, C16.2, C19.2, C23.1, C29.2, J3.18, J3.19, L1.1, L4.2, R7.2, R8.2, R15.2, U1.20 (VDD3P3_RTC), U1.46 (VDD3P3_CPU), U1.55 (VDDA@1), U1.56 (VDDA@2), U3.A2 (VOS), U9.12 (3V3_OUT)
/03 XIAO ESP32-S3-Sense/VDD_SPI: C22.2, U1.29 (VDD_SPI), U5.8 (VCC)
/03 XIAO ESP32-S3-Sense/VIN: C3.1, C4.1, C30.2, D2.-, J3.15, J3.30, Q1.3 (S), U3.B1 (VIN), U3.C2 (EN)
GND: ANT1.GND1, ANT1.GND2, C1.1, C2.1, C3.2, C4.2, C5.1, C6.1, C7.2, C8.1, C9.1, C10.2, C11.1, C12.1, C13.1, C14.1, C15.1, C16.1, C17.1, C18.1, C19.1, C20.1, C21.1, C22.1, C23.2, C25.2, C26.2, C28.1, C29.1, C30.1, GND0.1 (T), J3.1, J3.17, J3.28, J3.29, J3.31, J3.33, J3.34, K1.2 (B0), K1.4 (B1), K2.2 (B0), K2.4 (B1), R1.1, R2.2, R9.1, R10.1, R13.1, TP1.T, U1.57 (GND), U3.A1 (GND), U4.B1 (F), U4.C2 (GND), U5.4 (GND), U9.13 (GND), USB0.A1_B12 (A1/B12/GND), USB0.B1_A12 (B1/A12/GND), USB0.S1, USB0.S2, USB0.S3, USB0.S4, USB0.S5 (S1), USB0.S6 (S2), X1.2 (GND), X1.4 (GND@1)
unnamed: ANT1.D, C17.2, L2.1, L3.2
unnamed: C20.2, L3.1
unnamed: CHG0.+, R11.2
unnamed: D3.+, R15.1
unnamed: C18.2, L2.2, U1.1 (LNA_IN)
unnamed: R6.1, U1.49 (U0TXD)
unnamed: C15.2, L1.2, U1.2 (VDD3P3@1), U1.3 (VDD3P3@2)
unnamed: C8.2, U1.53 (XTAL_N), X1.1 (X1)
unnamed: L5.1, U1.54 (XTAL_P)
unnamed: R13.2, U3.C1 (MODE)
unnamed: L4.1, U3.B2 (SW)
unnamed: R10.2, U4.C1 (IREF)
unnamed: CHG0.-, U4.B2 (NCHG)
unnamed: R1.2, USB0.A5 (A5/CC1)
unnamed: R2.1, USB0.B5 (B5/CC2)
unnamed: C7.1, L5.2, X1.3 (X2)

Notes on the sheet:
SD Card
Layout note： Bottom
Camera
ICharge=24000/220K=110mA
MIC
Layout note： Same position as XIAO-C3
Imax=600mA
3.7~5V
0.3A/Pin
8MB Flash GD25Q64ENIGR


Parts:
U7: LOGO_CC_BY-SA_4.0


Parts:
U2: LOGO_CC_BY-SA_4.0

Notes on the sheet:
wei.Xing
Initial Version
R5 changed from 0R to L5_24nH
2.Adjust C30 and C16 inward
v1.1
v1.3
Linus.Liao
v1.0
2025/10/21
2023/7/25
v1.2
2023/1/4
1.Remove the silkscreen for K1, K2, U3, and U4
Optimize the distance from the positioning hole of the shield to the pads on both sides
2023/3/27



Board: 4 copper layers, 17.8 x 21.1 mm, 70 parts (10 on the bottom side), 62 nets.

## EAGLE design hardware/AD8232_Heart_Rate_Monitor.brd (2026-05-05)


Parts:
C1: 1.5nF; 0603-CAP
C2: 1nF; 0603-CAP
C3: 10nF; 0603-CAP
C4, C6: 0.33uF; 0805
C5: 0.1uF; 0603-CAP
C7: 0.1uf; 0603-CAP
D1: RED; LED-0603
FID1, FID2: FIDUCIAL1X2; FIDUCIAL-1X2
FRAME1: FRAME-LETTER; CREATIVE_COMMONS
JP1: M03PTH; 1X03
JP2: AUDIO-JACKSMD2; AUDIO-JACK-3.5MM-SMD
JP3: M06SIP; 1X06
LOGO1: OSHW-LOGOS; OSHW-LOGO-S
LOGO2: SFE_LOGO_NAME_FLAME.1_INCH; SFE_LOGO_NAME_FLAME_.1
R1, R2, R10, R11, R13, R14: 10M; 0603-RES
R3, R4: 180k; 0603-RES
R5: 360k; 0603-RES
R6, R7, R9: 1M; 0603-RES
R8: 100k; 0603-RES
R12: 1.4M; 0603-RES
R15: 10K; 0603-RES
R16: 1k; 0603-RES
R17, R19: 0; 0603
R18, R20: DNP; 0603
SJ4: LED DISABLE; SJ_2S-TRACE
STANDOFF1, STANDOFF2, STANDOFF3, STANDOFF4: STAND-OFF
U1: AD8232; LFCSP_20

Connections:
3.3V: C5.1, JP3.2, R10.1, R15.2, R17.1, R20.2, U1.15 (FR), U1.17 (+VS)
GND: C5.2, C7.2, JP3.1, R14.1, R19.1, SJ4.1, U1.16 (GND), U1.PAD (GND_PAD)
LA: JP1.2, JP2.RING (RIGHT), R1.1, R3.1
LO+: JP3.5, U1.12 (LO+)
LO-: JP3.4, U1.11 (LO-)
unnamed: R3.2, U1.2 (+IN)
unnamed: R4.2, U1.3 (-IN)
unnamed: C3.2, R7.2, U1.7 (OPAMP+)
unnamed: C4.2, R11.1, U1.20 (HPSENSE)
unnamed: C7.1, R10.2, R14.2, U1.18 (REFIN)
unnamed: D1.A, R16.1
unnamed: R8.1, R9.2, U1.9 (OPAMP-)
unnamed: R6.2, R13.1, U1.19 (IAOUT)
unnamed: C1.2, R6.1, R7.1
unnamed: D1.C, SJ4.2
unnamed: R19.2, R20.1, U1.14 (AC/!DC)
unnamed: C4.1, U1.1 (HPDRIVE)
unnamed: R11.2, R12.1, R13.2
unnamed: C6.1, R12.2, R18.2, U1.6 (SW)
unnamed: C2.1, U1.4 (RLDFB)
unnamed: C2.2, R5.1, U1.5 (RLD)
unnamed: R1.2, R2.2, R17.2, R18.1
RA: JP1.3, JP2.SLEEVE, R2.1, R4.1
REFOUT: C3.1, C6.2, R8.2, U1.8 (REFOUT)
RL: JP1.1, JP2.TIP (LEFT), R5.2
SDN: JP3.6, R15.1, U1.13 (!SDN)
SIGNAL_OUT: C1.1, JP3.3, R9.1, R16.2, U1.10 (OUT)

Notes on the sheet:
Casey Kuhns
v10
Note: Cardiac Monitor Config


Board: 2 copper layers, 35.6 x 27.9 mm, 42 parts (0 on the bottom side), 27 nets.

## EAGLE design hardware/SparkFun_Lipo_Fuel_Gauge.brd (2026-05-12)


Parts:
C1: 1.0uF; 0402-TIGHT
C2: 10nF; 0402-TIGHT
FRAME1: FRAME-LETTER; CREATIVE_COMMONS
I2C: JUMPER-SMT_3_2-NC_TRACE_SILK; SMT-JUMPER_3_2-NC_TRACE_SILK
JP1: input; JST-2-SMD
JP2, JP4: CONN_031X03_NO_SILK; 1X03_NO_SILK
JP3: SFE_LOGO_FLAME.1_INCH; SFE_LOGO_FLAME_.1
JP5: CONN_021X02_NO_SILK; 1X02_NO_SILK
JP6, JP7, JP8, JP9: FIDUCIALUFIDUCIAL; FIDUCIAL-MICRO
LOGO1: SFE_LOGO_NAME_FLAMEBLANK; BLANK
R1: 1k; 0402-TIGHT
R2: 100; 0402-TIGHT
R3, R4, R5, R6: 2.2k; 0402-TIGHT
U2: MAX1704X; TDFN-8
U$1: OSHW-LOGOS; OSHW-LOGO-S

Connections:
ALT: JP4.3, R3.1, U2.5 (ALT)
GND: C1.2, C2.2, JP1.1 (-), JP4.2, JP5.2, R4.1, U2.1 (CTG), U2.4 (GND), U2.EP (GND)
unnamed: I2C.3, R6.2
unnamed: C1.1, R1.2, U2.2 (CELL)
unnamed: I2C.1, R5.2
QST: JP2.3, R4.2, U2.6 (QST)
SCL: JP2.2, R5.1, U2.7 (SCL)
SDA: JP2.1, R6.1, U2.8 (SDA)
VCC: I2C.2, JP4.1, R3.2
VDD: C2.1, R2.1, U2.3 (VDD)
V_BATT: JP1.2 (+), JP5.1, R1.1, R2.2

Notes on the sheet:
v12
Aaron Weiss
Revised by:
Dryw Wade
Connectors
Fuel Gauge
WARNING
Only use with single cell LiPo batteries! This chip is not intended for multi-cell batteries!
V_BATT Range: 2.5V-4.5V
VCC Max: 5.5V
Cut traces to remove I2C pullups



Board: 2 copper layers, 10.2 x 24.1 mm, 29 parts (15 on the bottom side), 11 nets.

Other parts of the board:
U$2: SDA0
U$3: SCL0
U$4: QST0
U$5: VCC0
U$6: GND0
U$7: ALT0
U$8: #I2C#0

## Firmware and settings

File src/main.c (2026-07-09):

// Stub principal — los includes pesados sólo se traen cuando el env
// correspondiente lo activa, para que envs livianos (p.ej. capture_c3)
// no necesiten LVGL ni los drivers del display.
#if defined(ENV_MAIN_APP) || defined(ENV_MAIN_NOTOUCH)
#include "supaclock_app.h"

void app_main(void) {
    supaclock_app_run();
}
#endif

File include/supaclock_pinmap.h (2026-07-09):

/**
 * @file supaclock_pinmap.h
 * @brief Mapa central de pines para el carrier SupaClock v1 (XIAO ESP32-S3 DIP).
 *
 * Derivado de hardware/SupaClock_Carrier/netlist.net (rev v1.0, 2026-05-11).
 * Es la única fuente de verdad: cualquier driver que necesite un GPIO debe
 * incluir este header en vez de hard-codear el número.
 *
 * Convención de los headers de la XIAO ESP32-S3 (DIP-14, vista superior con
 * USB-C hacia arriba):
 *
 *     ┌───────────────┐
 *     │ 1  GPIO1  D0  │ ← ECG_OUT          (ADC1_CH0)
 *     │ 2  GPIO2  D1  │ ← ECG_SDN
 *     │ 3  GPIO3  D2  │ ← BLK_PWM          (LEDC)
 *     │ 4  GPIO4  D3  │ ← SPI_DC
 *     │ 5  GPIO5  D4  │ ← I2C_SDA
 *     │ 6  GPIO6  D5  │ ← I2C_SCL
 *     │ 7  GPIO43 D6  │ ← BTN_NEXT         (era U0TXD, requiere USB-CDC)
 *     │ 8  GPIO44 D7  │ ← SPI_CS           (era U0RXD, requiere USB-CDC)
 *     │ 9  GPIO7  D8  │ ← SPI_SCK
 *     │10  GPIO8  D9  │ ← BTN_SELECT
 *     │11  GPIO9  D10 │ ← SPI_MOSI
 *     │12  3V3        │
 *     │13  GND        │
 *     │14  VBUS       │  (no conectado en el carrier)
 *     └───────────────┘
 *
 * NOTA: La consola debe ir por USB-Serial-JTAG
 *       (CONFIG_ESP_CONSOLE_USB_SERIAL_JTAG=y) porque GPIO43/44 están
 *       ocupados por botón y CS del display.
 *
 * NOTA: BMI160 INT1 NO está cableada en este carrier (J5 pin 6 = NC).
 *       El HAR debe leer la FIFO por polling (sin IRQ de hardware).
 */
#ifndef SUPACLOCK_PINMAP_H
#define SUPACLOCK_PINMAP_H

/*
 * Selector de board:
 *   -D SUPACLOCK_BOARD_C3=1  → ESP32-C3 SuperMini, banco de captura de IMU
 *                              para entrenar el HAR (semana del 2026-05-23).
 *   (default)                → XIAO ESP32-S3 sobre el carrier v1.
 */

#if defined(SUPACLOCK_BOARD_C3)

/* ──────────────────── ESP32-C3 SuperMini (bench HAR capture) ────────────────────
 * Sólo el BMI160 está conectado vía I2C. Display / ECG / botones quedan
 * deshabilitados; los drivers que referencien SPI / ADC / BTN no se compilan
 * en el env capture_c3.
 */
#define SUPA_PIN_I2C_SDA        8       /* GPIO8 = SDA por default en C3 */
#define SUPA_PIN_I2C_SCL        9       /* GPIO9 = SCL por default en C3 */

#define SUPA_PIN_BMI160_INT1    (-1)    /* No usamos IRQ en bench */

/* Resto deshabilitado en C3 (los envs de capture no los compilan). */
#define SUPA_PIN_BTN_NEXT       (-1)
#define SUPA_PIN_BTN_SELECT     (-1)
#define SUPA_PIN_SPI_MOSI       (-1)
#define SUPA_PIN_SPI_SCK        (-1)
#define SUPA_PIN_SPI_CS         (-1)
#define SUPA_PIN_SPI_DC         (-1)
#define SUPA_PIN_LCD_RST        (-1)
#define SUPA_PIN_LCD_BLK        (-1)
#define SUPA_PIN_ECG_OUT        (-1)
#define SUPA_PIN_ECG_SDN        (-1)
#define SUPA_PIN_ECG_LO_PLUS    (-1)
#define SUPA_PIN_ECG_LO_MINUS   (-1)
#define SUPA_ADC_CHANNEL_ECG    ADC_CHANNEL_0
#define SUPA_ADC_UNIT_ECG       ADC_UNIT_1

#else  /* ──────────────── XIAO ESP32-S3 carrier v1 (default) ──────────────── */

/* Convención de los headers de la XIAO ESP32-S3 (DIP-14, vista superior con
 * USB-C hacia arriba):
 *
 *     ┌───────────────┐
 *     │ 1  GPIO1  D0  │ ← ECG_OUT          (ADC1_CH0)
 *     │ 2  GPIO2  D1  │ ← BLK_PWM          (LEDC)
 *     │ 3  GPIO3  D2  │ ← ECG_SDN          (Strapping pin JTAG)
 *     │ 4  GPIO4  D3  │ ← SPI_DC
 *     │ 5  GPIO5  D4  │ ← I2C_SDA
 *     │ 6  GPIO6  D5  │ ← I2C_SCL
 *     │ 7  GPIO43 D6  │ ← BTN_NEXT         (era U0TXD, requiere USB-CDC)
 *     │ 8  GPIO44 D7  │ ← SPI_CS           (era U0RXD, requiere USB-CDC)
 *     │ 9  GPIO7  D8  │ ← SPI_SCK
 *     │10  GPIO8  D9  │ ← BTN_SELECT
 *     │11  GPIO9  D10 │ ← SPI_MOSI
 *     │12  3V3        │
 *     │13  GND        │
 *     │14  VBUS       │  (no conectado en el carrier)
 *     └───────────────┘
 *
 * NOTA: Consola debe ir por USB-Serial-JTAG porque GPIO43/44 están ocupados.
 * NOTA: BMI160 INT1 NO está cableada en este carrier (J5 pin 6 = NC).
 */

/* ───── I2C compartido (BMI160, MAX30102, MAX30205, MAX17048) ───── */
#define SUPA_PIN_I2C_SDA        5
#define SUPA_PIN_I2C_SCL        6

/* ───── SPI para ST7789 1.69" ───── */
#define SUPA_PIN_SPI_MOSI       9
#define SUPA_PIN_SPI_SCK        7
#define SUPA_PIN_SPI_CS         44
#define SUPA_PIN_SPI_DC         4
#define SUPA_PIN_LCD_RST        (-1)   /* no cableado → reset por software */
#define SUPA_PIN_LCD_BLK        3      /* LEDC PWM */

/* ───── AD8232 ECG ───── */
#define SUPA_PIN_ECG_OUT        1      /* ADC1_CH0 (S3) */
#define SUPA_PIN_ECG_SDN        2     /* Pin de shutdown del ECG, activo alto para simplificar el control */
#define SUPA_PIN_ECG_LO_PLUS    (-1)
#define SUPA_PIN_ECG_LO_MINUS   (-1)
#define SUPA_ADC_CHANNEL_ECG    ADC_CHANNEL_0
#define SUPA_ADC_UNIT_ECG       ADC_UNIT_1

/* ───── Botones ───── */
#define SUPA_PIN_BTN_NEXT       43
#define SUPA_PIN_BTN_SELECT     8

/* ───── IMU INT1 (BMI160) ───── */
#define SUPA_PIN_BMI160_INT1    (-1)   /* no cableada en carrier v1 */
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

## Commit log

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2026-04-18 feat: integrate BMI160 driver, add step algorithm, update documentation, and expand testing and simulation tools.
    [supaclock_20260416_190430.csv, supaclock_20260416_191153.csv, supaclock_20260416_191300.csv]
2026-04-23 refactor: update BLE telemetry protocol, add performance testing scripts, and manage tool output files.
    [supaclock_ecg_20260422_194036.csv, supaclock_ecg_20260422_194732.csv]
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2026-04-30 feat: improve MAX17048 stability with EMA filtering, hibernate configuration, and POR handling while increasing AD8232 buffer size
    [test_fuel_gauge.c, test_general.c]
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2026-04-30 docs: update power consumption chart data and correct LDO regulator model name in presentation files
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2026-05-04 Informe 2: Cambios de redacción, análisis comparativo frente a la industria y modificación de algunas pruebas
    [Rubrica_informe_avance_2.xlsx]
2026-05-05 Add TP4056 schematic and USB Micro-B footprint
    - Created a new schematic file for the TP4056 circuit in KiCad format, including components such as capacitors, resistors, LEDs, connectors, and the TP4056 IC itself.
    - Added a footprint for the USB Micro-B connector, detailing its dimensions and pin configurations, suitable for surface mount applications.
    [AD8232_Heart_Rate_Monitor-Panel-v10.brd, AD8232_Heart_Rate_Monitor-Panel-v10_WINDOW_PANNED_PASTE.brd, AD8232_Heart_Rate_Monitor.brd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]
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2026-05-12 feat: Update SupaClock Carrier project settings and add tuning profiles
    - Disabled default application for footprint barcodes and dimensions.
    - Introduced new warnings for footprint symbol field mismatches and missing tuning profiles.
    - Added support for tuning profiles in design settings.
    - Updated IPC2581 settings with a new schematic revision field.
    - Enhanced error handling for various design rule checks.
    - Incremented project version to 5 and added tuning profiles metadata.
    - Included new annotation settings and top-level sheet information in schematic.
    [SupaClock_Carrier.kicad_pcb]
2026-05-13 Add script to fix THT pad sizes for LPKF CNC fabrication
    - Introduced `fix_pads_lpkf.py` to enlarge THT pad annular rings to meet LPKF ProtoMat S64 minimum requirements.
    - Implemented board-level design rules for clearance, track width, and via dimensions.
    - Fixed THT pad sizes and ensured pad shapes are consistent.
    - Included verification checks for pad sizes and design rules after modifications.
2026-05-15 Update design rule severities in SupaClock_Carrier project
    - Changed clearance rule severity from error to ignore
    - Changed nonmirrored text on back layer rule severity from warning to ignore
    - Updated silk over copper and silk overlap rule severities from warning to ignore
    [SupaClock_Carrier.kicad_pcb]
2026-05-15 Update design rules and footprint for MAX30102
    - Increased minimum through hole diameter from 0.8mm to 1.0mm.
    - Adjusted minimum via annular width from 0.6mm to 0.4mm and minimum via diameter from 2.0mm to 1.8mm.
    - Modified the footprint for MAX30102_Castellated_1x4 by changing the yard dimensions and adding additional lines for improved clarity.
    [SupaClock_Carrier.kicad_pcb]
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2026-05-15 Add DRC JSON files for SupaClock Carrier: drc_post_relax.json and drc_post_thtswap.json
    - Created drc_post_relax.json with 509 violations and warnings related to thermal relief, text dimensions, and footprint mismatches.
    - Created drc_post_thtswap.json with 653 violations and warnings, including unconnected items, hole size issues, and silkscreen clearance violations.
    - Both files include ignored checks and are formatted according to the KiCad DRC schema.
    [SupaClock_Carrier.kicad_pcb, SupaClock_Carrier.kicad_sch]
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2026-05-23 feat(mechanical): add SupaClock V2 concept design with enhanced aesthetics
    - Introduced `supaclock_v2_concept.scad` for visual representation of the new design.
    - Added `supaclock_v2_dimensions.md` detailing critical dimensions for Fusion 360 reconstruction.
    - Created `supaclock_v2_top_case.scad` for the functional top case with improved features.
    - Generated corresponding STL files for both concept and top case.
    - Updated partitioning for ESP32-C3 SuperMini in `partitions_c3.csv`.
    - Migration to ESP32 S3
    [SupaClock_Carrier.kicad_pcb, bottom_cuts.dxf, bottom_outer.dxf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]
2026-05-25 Add schematic generation and symbol extraction for SupaClock_Display_Adapter
    - Implemented build_schematic.py to generate the SupaClock_Display_Adapter.kicad_sch file from a predefined library of symbols, including placement and wiring of components.
    - Created extract_symbols.sh to extract necessary symbols from KiCad's symbol libraries and format them for the schematic.
    - Added fp-lib-table and sym-lib-table files to define custom footprints and symbol libraries for the project.
    [SupaClock_Display_Adapter.kicad_pcb, SupaClock_Display_Adapter.kicad_sch]
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2026-05-26 Ajustes a modelo de ML para S3 y entrenamiento con datos medidos
    [supaclock_imu_running_20260525_181353.csv]
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2026-05-28 Add UI font and theme management with NVS persistence
    - Introduced custom UI fonts in `ui_fonts.h` for better text rendering.
    - Created `ui_theme` module with color themes, allowing users to switch themes.
    - Implemented NVS storage for persisting the active theme across sessions.
    - Added functionality to retrieve and set themes, including a count of available themes.
    - Updated `test_general.c` to enhance screen transition animations.
    [SupaClock_Carrier.kicad_pcb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]
2026-05-28 Add header file for Supaclock UI module
    - Introduced `supaclock_ui.h` to define the UI interface for the Supaclock application.
    - Added function prototypes for UI initialization, action configuration, button event handling, and periodic UI updates.
    - Defined a structure for UI actions to handle power off and battery reset events.
    [main.c]
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2026-06-02 Refactor code structure and remove redundant sections for improved readability and maintainability
    [Rubrica_informes_avances_3.xlsx]
2026-06-15 Add large image files for project documentation
    - Added carcasas.png (7344 KB) to the Entrega3 documentation.
    - Added prototipopcb.png (8773 KB) to the Entrega3 documentation.
    [supaclock_v2_concept.stl, supaclock_v2_top_case.scad, supaclock_v2_top_case.stl]
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2026-06-25 feat: Add firmware handoff documentation and new HAR replay tool
    - Created `firmware_handoff_har.md` to outline app changes for firmware coordination, including TLV consumption, IMU cadence, and required artifacts.
    - Introduced `har_replay.py` script to re-run the HAR model on recorded sessions, normalizing IMU data and generating confusion matrices for model validation against manual labels.
    - Updated documentation to reflect changes in data handling and model inference processes.
    [generate_dxf_sketches.scad, supaclock_top_case.scad, supaclock_top_case.stl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]
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2026-07-09 Milestone pre-presentación: HAR real, deep sleep, watchface SPORT
    Firmware:
    - HAR pipeline funcional en TFLite Micro (float32) — antes caía a heurístico
    siempre "correr". Runner en har_model_runner.cpp con op resolver completo
    (Conv2D, MaxPool2D, Mean, FullyConnected, Softmax, Reshape, ExpandDims,
    Relu, Quantize, Dequantize). Blob linkeado strong-extern (era weak, el
    linker no lo pulleaba). Arena 512KB en PSRAM. Training script (S3) con
    fix de glob .csv.gz y decimation 100→50Hz de datos legacy.
    - Deep sleep robusto: RTC-GPIO pattern + RTC_PERIPH ON, ext1 wake en
    BTN_SELECT (GPIO8, único RTC-capable de la pinout actual). Hold-to-boot
    3s / force-reboot 6s. Suspend síncro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
    [train_har_cnn.py]
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

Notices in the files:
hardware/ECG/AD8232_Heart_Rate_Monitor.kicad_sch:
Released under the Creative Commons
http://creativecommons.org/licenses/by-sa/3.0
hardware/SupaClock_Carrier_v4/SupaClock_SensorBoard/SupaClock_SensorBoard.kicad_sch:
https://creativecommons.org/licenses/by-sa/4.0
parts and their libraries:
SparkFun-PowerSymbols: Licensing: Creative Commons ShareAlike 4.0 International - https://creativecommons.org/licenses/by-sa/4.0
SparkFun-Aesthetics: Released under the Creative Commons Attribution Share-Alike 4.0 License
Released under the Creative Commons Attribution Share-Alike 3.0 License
